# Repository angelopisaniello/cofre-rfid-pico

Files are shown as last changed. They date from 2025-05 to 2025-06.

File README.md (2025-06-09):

# Sistema de Gavetas Inteligentes com Abertura por RFID

## Descrição Geral
Este projeto foi desenvolvido como parte da disciplina **EEN251 - Microcontroladores e Sistemas Embarcados** do Instituto Mauá de Tecnologia.

## 👨‍💻 Integrantes da Equipe

| Nome | RA |
|---|---|
| Angelo Pisaniello Junior | 12.95003-3 |
| Danilo Di Fábio Bueno | 22.00028-3 |
| Daniel F. Soares | 22.01298-2 |

## Descrição do Projeto

O projeto consiste em um sistema embarcado para controle de três gavetas inteligentes com abertura por **RFID**, desenvolvido com o microcontrolador **Raspberry Pi Pico**. As gavetas possuem **solenóides** para travamento/abertura, e o sistema inclui ainda:

- **Teclado matricial** para comandos locais;
- **Display OLED** para exibição de mensagens;
- **LEDs e buzzer** para sinalização visual e sonora;
- **Sensores ópticos** para detecção de estado (aberta/fechada) das gavetas.

Este projeto tem aplicação potencial em **cofres de hotel**, **estações públicas de recarga de celular** ou **armários inteligentes**.

---

## 📋 Requisitos do Sistema

| ID | Requisito | Tipo |
|---|---|---|
| SR-01 | Ser composto por módulos prontos e de fácil acesso | Obrigatório  |
| SR-02 | Controlar a abertura de 3 gavetas de forma independente por meio de autenticação RFID | Obrigatório  |
| SR-03 | Travar e destravar as gavetas utilizando solenoides de 12V | Obrigatório  |
| SR-04 | Detectar o estado (aberta/fechada) de cada gaveta utilizando sensores ópticos | Obrigatório  |
| SR-05 | Fornecer feedback visual através de LEDs indicadores | Obrigatório  |
| SR-06 | Fornecer feedback sonoro através de buzzer | Obrigatório  |
| SR-07 | Permitir comandos e interação local por meio de teclado matricial | Obrigatório  |
| SR-08 | Exibir informações no display OLED (status, mensagens de operação) | Obrigatório  |
| SR-09 | Possuir sistema de proteção elétrica adequado (diodos flyback, MOSFETs para acionamento) | Obrigatório  |
| SR-10 | Ser alimentado por fonte de 12V com corrente suficiente para acionar os 3 solenoides | Obrigatório  |
| SR-11 | Ser montado em uma estrutura mecânica adequada (gaveteiro e caixa segura para o mecanismo) | Obrigatório  |
| SR-12 | Garantir a segurança contra sobreaquecimento dos solenoides com controle de tempo de acionamento  | Obrigatório  |
| SR-13 | Permitir futuras expansões, como comunicação com sistema externo (Wi-Fi, Bluetooth) | Desejável |
| SR-14 | Implementar modo de bloqueio total, caso tentativas de abertura não autorizadas sejam detectadas  | Desejável |

## 📝 Lista de Componentes

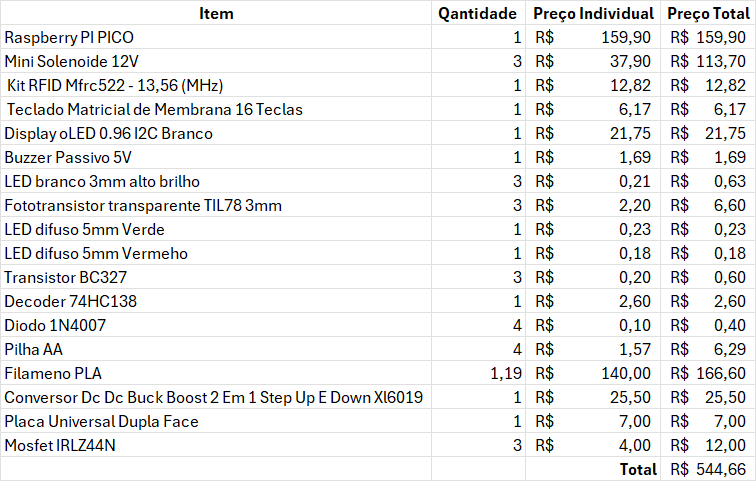
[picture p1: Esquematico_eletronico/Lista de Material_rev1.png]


## Diagrama de Blocos
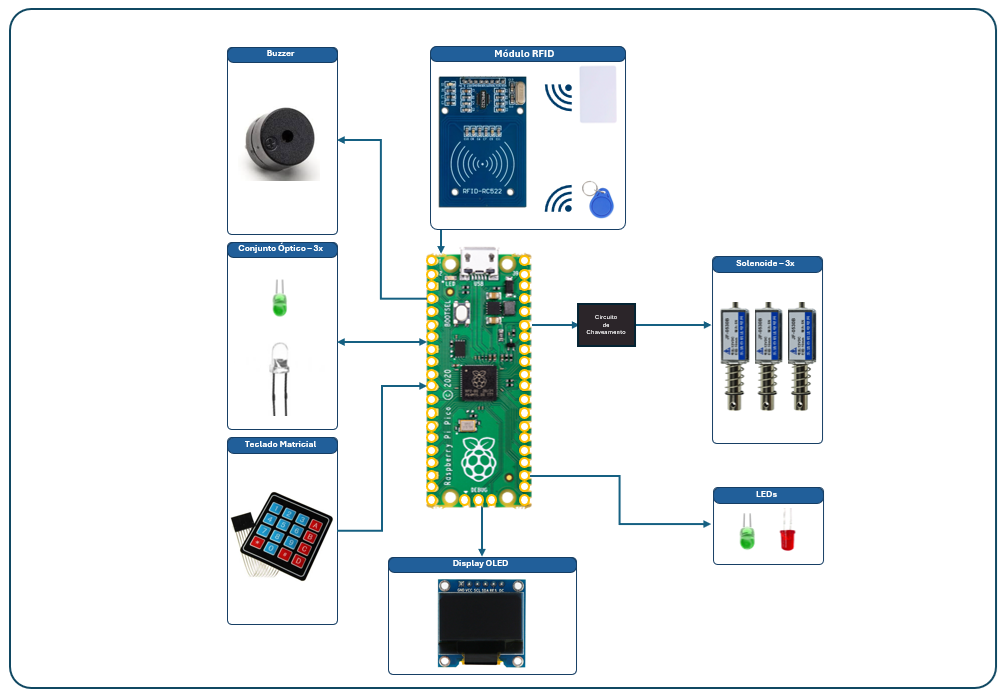
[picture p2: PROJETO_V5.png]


## 📥 Esquemáticos do Circuito Eletrônico

Os diagramas do circuito eletrônico do projeto foram desenvolvidos utilizando o software **KiCad EDA 9.0.2**.

- [Esquemático - Módulo de Controle](https://github.com/angelopisaniello/cofre-rfid-pico/blob/main/Esquematico_eletronico/proj1_sch01.pdf)
- [Esquemático - Módulo de Potência](https://github.com/angelopisaniello/cofre-rfid-pico/blob/main/Esquematico_eletronico/proj1_sch02.pdf)

Os esquemáticos incluem todos os componentes principais do sistema: Raspberry Pi Pico, RFID, LEDs de sinalização, drivers MOSFET, sensores ópticos, entre outros.

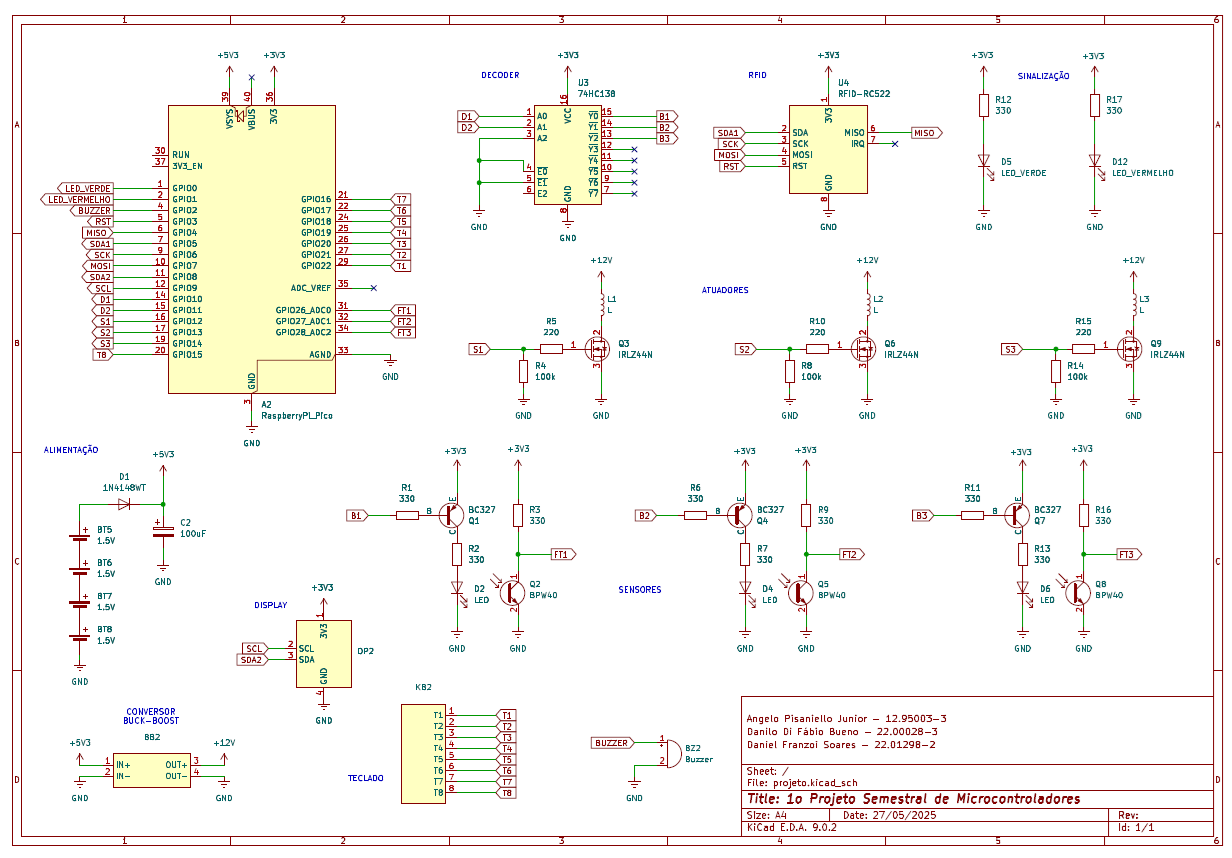
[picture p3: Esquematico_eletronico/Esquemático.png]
.

## 📷 Visualização do Circuito Montado

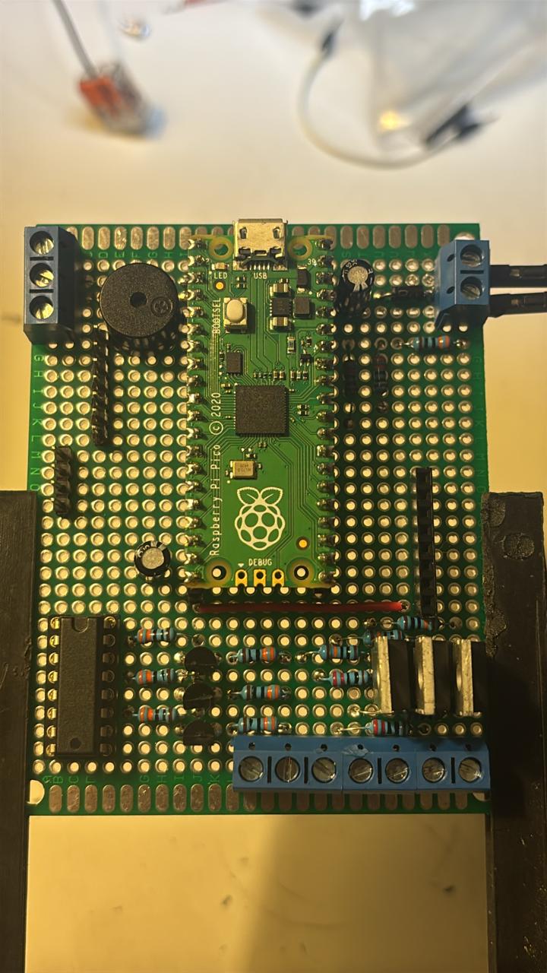
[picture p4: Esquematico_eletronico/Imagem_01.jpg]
image alt
.

## 🛠️ Projeto Mecânico das Gavetas

O projeto das peças mecânicas foi desenvolvido utilizando o software **Autodesk Fusion 360**, versão **2601.1.37 x86_64**, com plano **Estudante**. O ambiente de modelagem foi realizado no **Windows 11 Pro 24H2**.

As peças foram concebidas visando **facilidade de fabricação e montagem**, sendo idealizadas para **impressão 3D** utilizando o material **PLA (Ácido Polilático)**.

### 🎯 Motivos para a escolha do PLA:
- Excelente **custo-benefício**.
- **Facilidade de impressão**, mesmo em impressoras 3D domésticas.
- **Boa resistência mecânica** e **rigidez**, adequada para a estrutura das gavetas.
- Material **biodegradável** e com baixo impacto ambiental.
- **Acabamento estético** superior, com superfície lisa e sem necessidade de pós-processamento complexo.

### 🖥️ Por que escolhemos o Autodesk Fusion 360?
- Ferramenta **profissional e amplamente utilizada** na indústria.
- Permite integração completa entre **modelagem 3D**, **simulações** e **geração de arquivos para impressão (STL)**.
- Licença gratuita para **uso educacional**, ideal para o desenvolvimento acadêmico.
- Ambiente intuitivo, com recursos de **parametrização** e **colaboração em nuvem**.

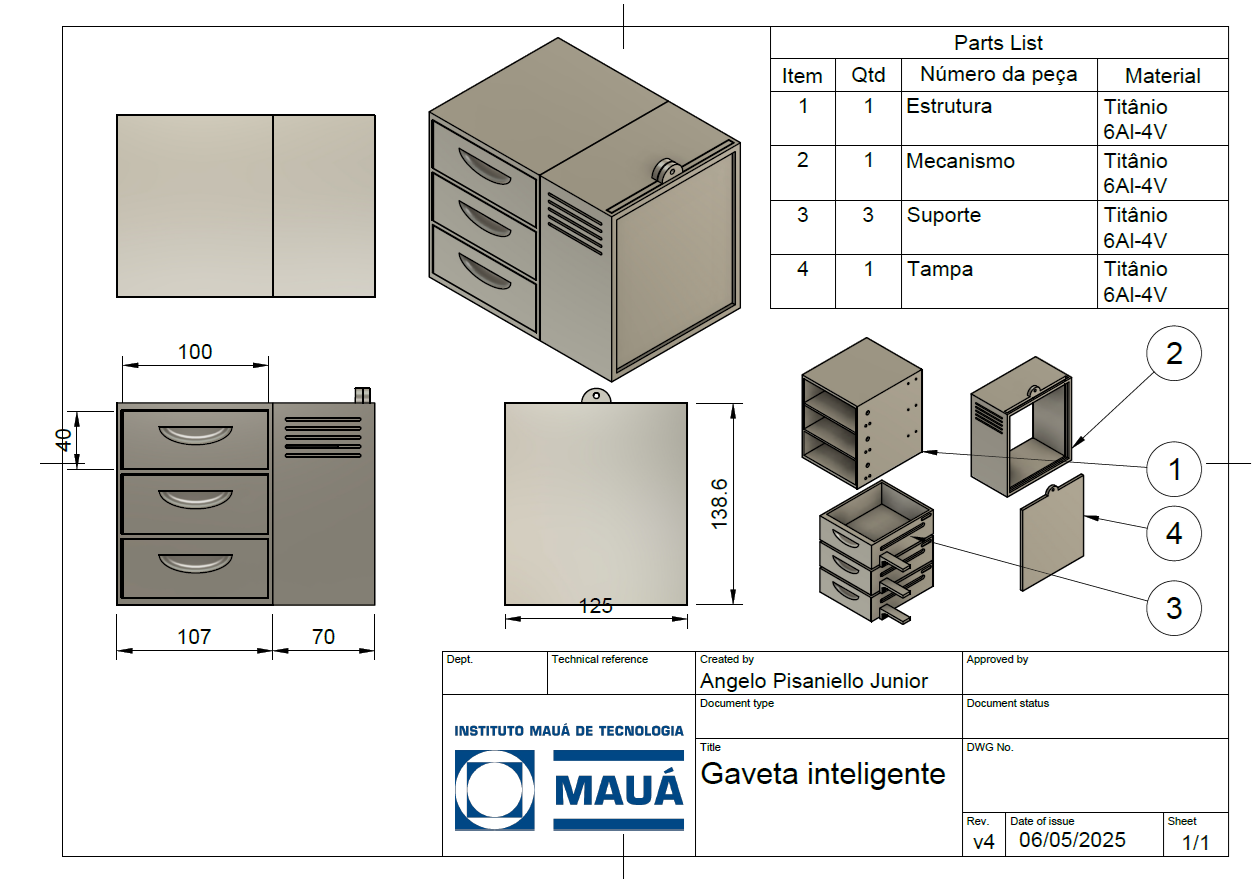
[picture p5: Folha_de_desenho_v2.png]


### 🔐🗄️ Imagem do Produto Final

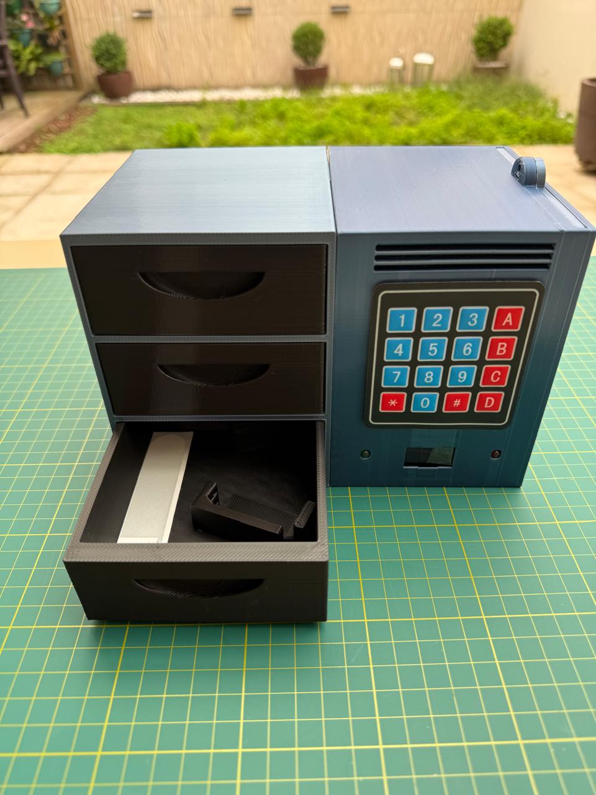
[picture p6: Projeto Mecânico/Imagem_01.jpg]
image alt


- [Arquivo do Projeto do Fusion 360](https://github.com/angelopisaniello/cofre-rfid-pico/blob/8d926f475f4df262f432c6a18744f179cbe58f7a/Projeto%20Mec%C3%A2nico/Angelo%20v4%20v16%20v1.f3d)

## Vídeo Explicativo

- [Link do Youtube](https://youtu.be/eFmRIbqSjfY

## ✅ Conclusão

O projeto apresentado integra hardware, software embarcado e projeto mecânico para demonstrar um sistema de controle de gavetas inteligentes com autenticação por RFID. A solução proposta tem aplicações práticas em segurança e automação, e poderá ser expandida para novas funcionalidades como controle remoto via rede e sensores adicionais.

> Projeto desenvolvido para a disciplina EEN251 - Microcontroladores e Sistemas Embarcados | Instituto Mauá de Tecnologia.

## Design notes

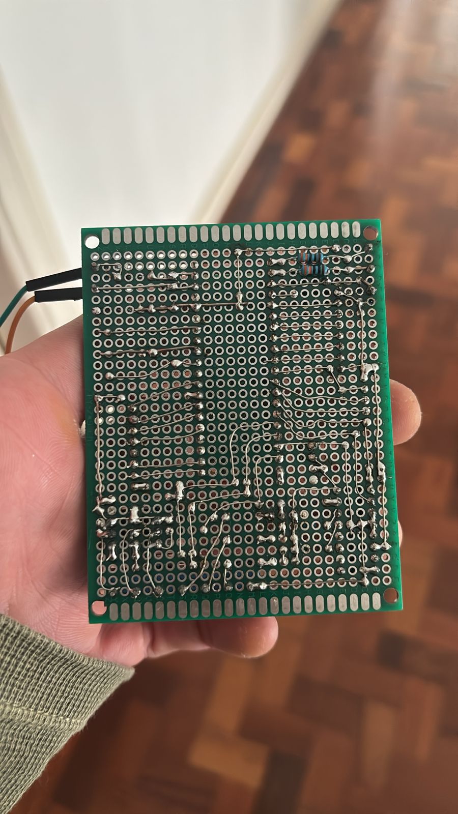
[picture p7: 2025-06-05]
Esquematico_eletronico/Imagem_02.jpg

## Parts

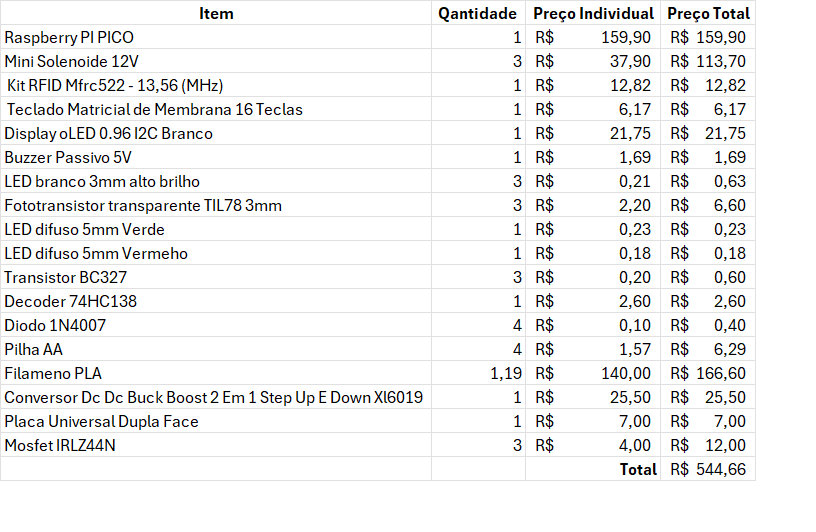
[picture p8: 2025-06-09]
Esquematico_eletronico/Lista de Material.png

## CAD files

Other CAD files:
Projeto Mecânico/Angelo v4 v16 v1.f3d

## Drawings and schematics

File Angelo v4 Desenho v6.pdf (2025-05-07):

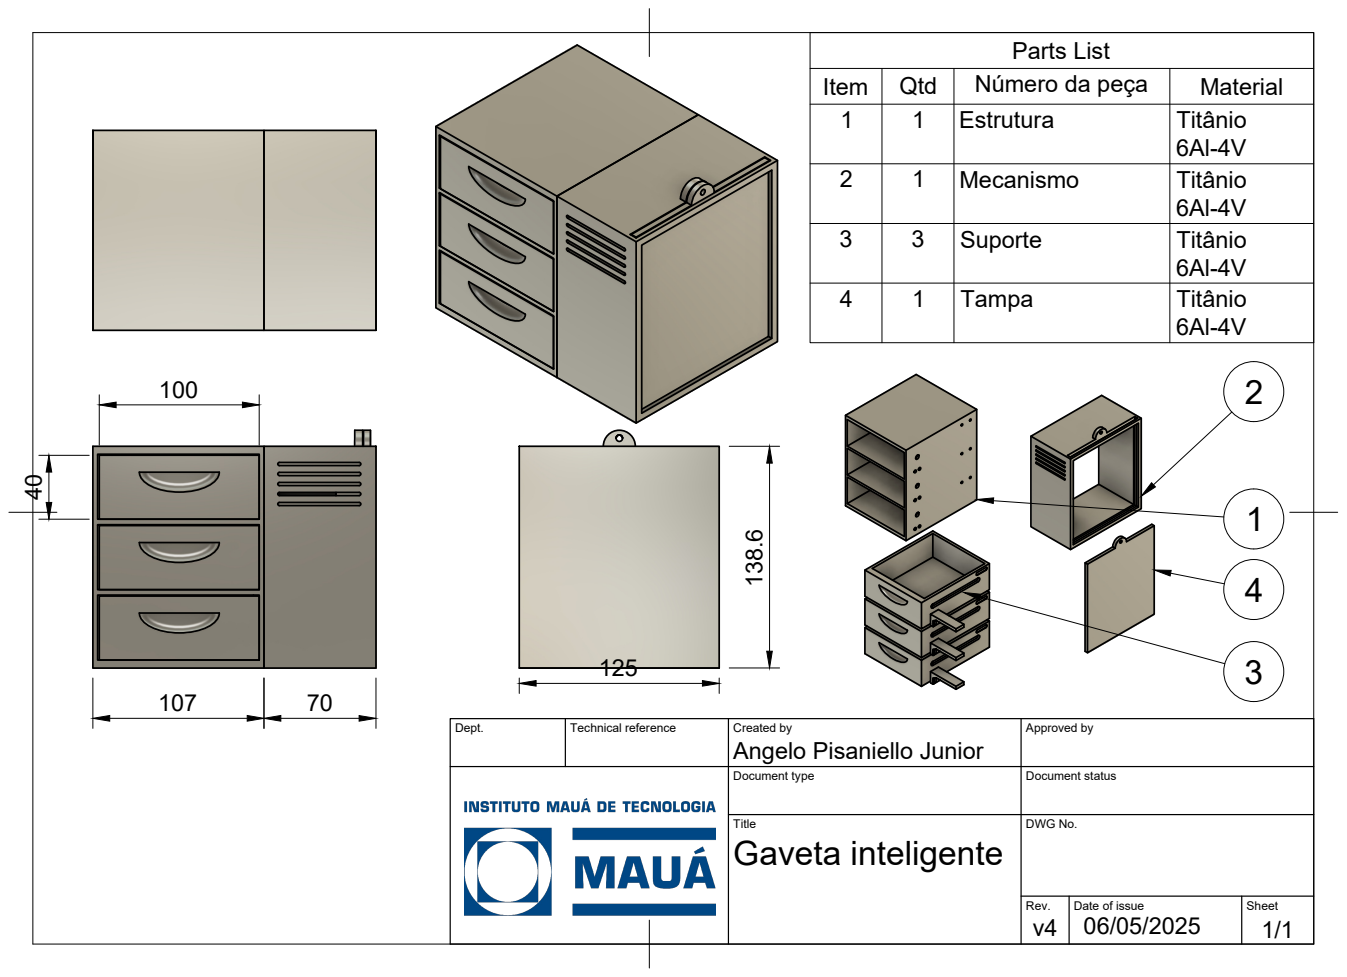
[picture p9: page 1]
Parts List

Item | Qtd | Número da peça | Material
1 | 1 | Estrutura | Titânio 6Al-4V

2 | 1 | Mecanismo | Titânio 6Al-4V

3 | 3 | Suporte | Titânio 6Al-4V

4 | 1 | Tampa | Titânio 6Al-4V

Angelo Pisaniello Junior 138.6

Dept. | Technical reference | Created by | Approved by

Document type | Document status

Title Gaveta inteligente | DWG No.

Rev. v4 | Date of issue 06/05/2025 | Sheet 1/1

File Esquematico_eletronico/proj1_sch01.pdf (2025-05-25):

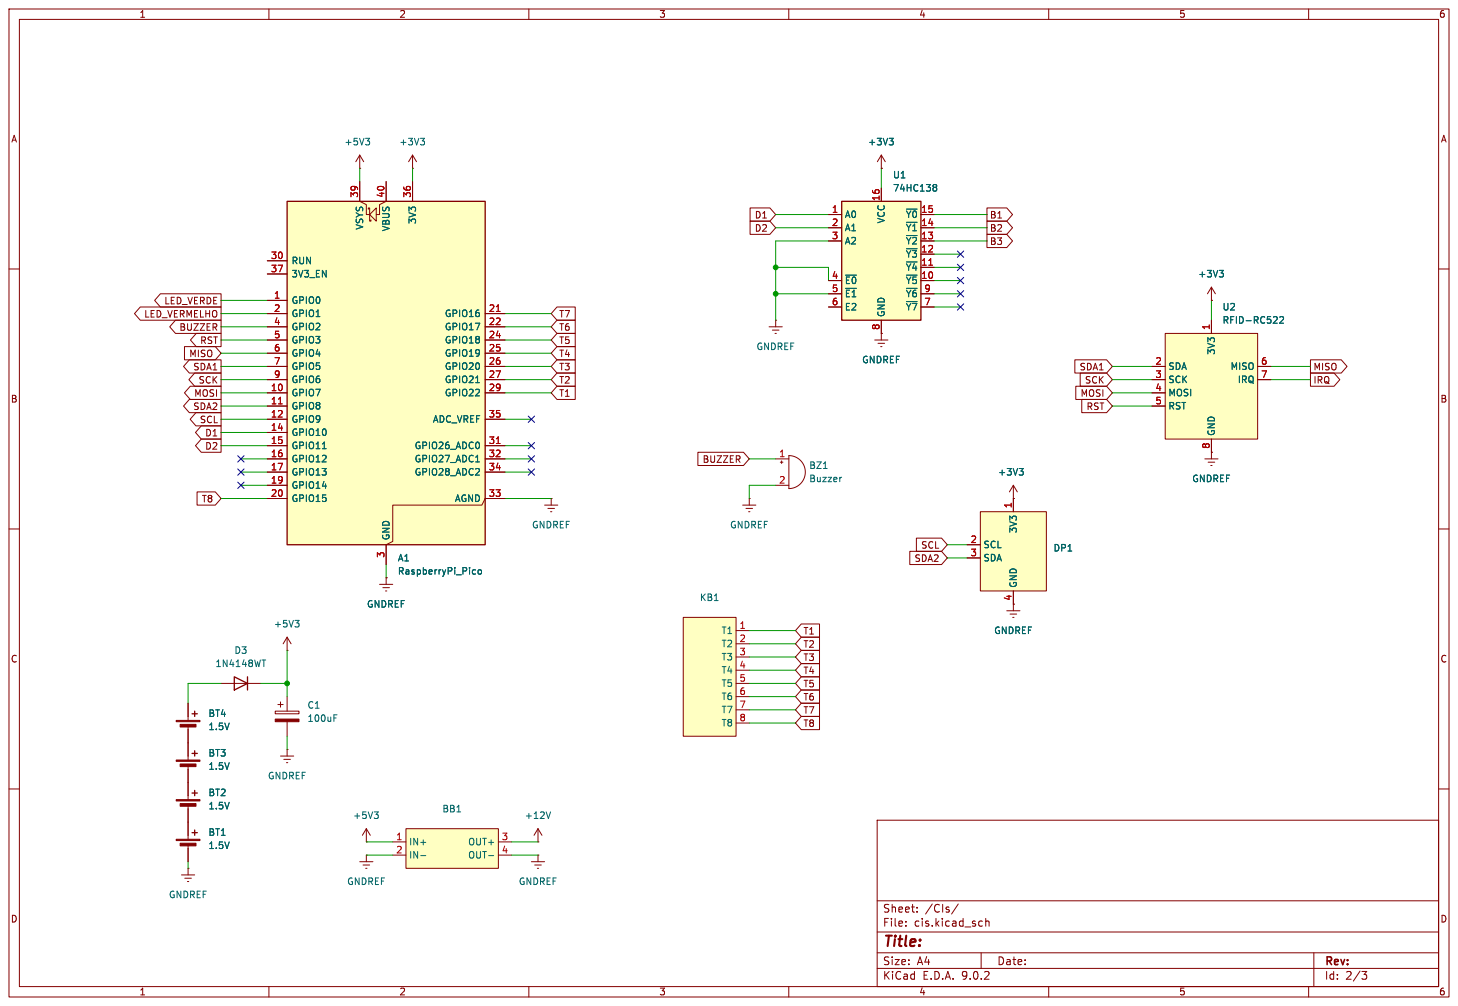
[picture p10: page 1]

Id: 2/3 Title: File: cis.kicad_sch Sheet: /CIs/

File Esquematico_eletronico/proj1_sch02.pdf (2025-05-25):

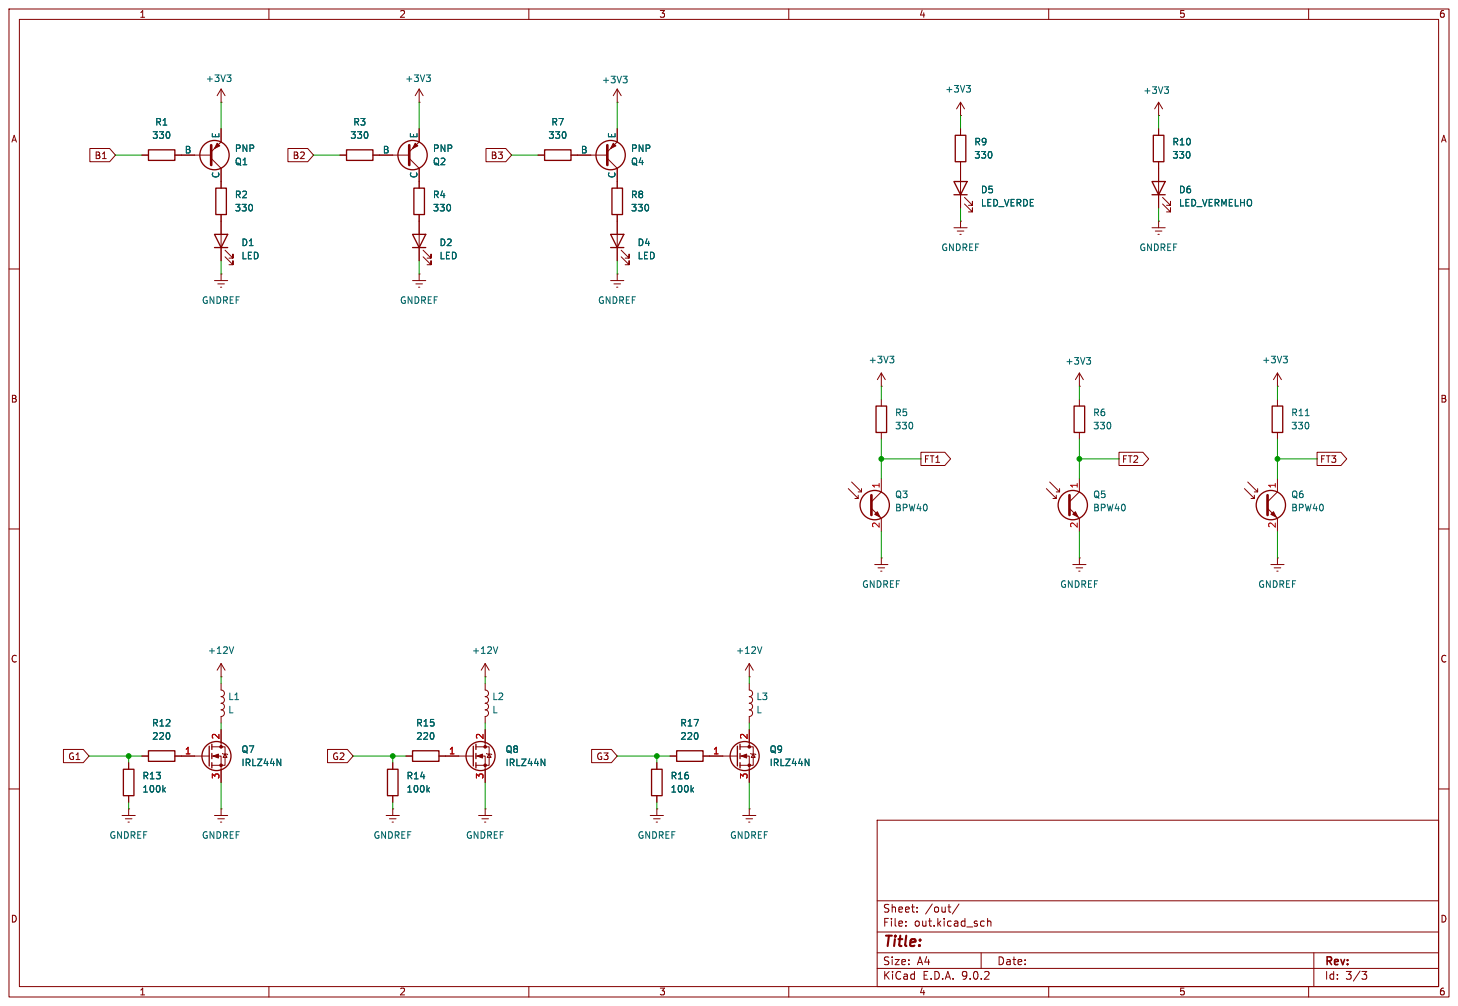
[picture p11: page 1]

Id: 3/3 Title: File: out.kicad_sch Sheet: /out/

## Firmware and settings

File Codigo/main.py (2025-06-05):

# Bibliotecas:
from machine import ADC, Pin 	# ADC =, IOs
import time 	# Temporizacao
import utime 	# Temporizacao
from machine import RTC # Real Time Clock
from machine import I2C 	# I2C
from mfrc522 import MFRC522 # RFID
from ssd1306 import SSD1306_I2C # Display OLED
#---------------------------------------------------------------------------------------------

# Variaveis globais:
WIDTH =128 
HEIGHT= 64
ST = 250 # Tempo de atualizacao em ms
usuarios = { 111111111: "Angelo", 1587063440:"Daniel", 2307218261: "Danilo"} # Dicionarios para os usuarios
gavetas = { "Angelo" : 1, "Daniel": 2, "Danilo": 3} # Dicionario para as gavetas
teclas = [
    ['1', '3', 'A', '2'],
    ['4', '6', 'B', '5'],
    ['7', '9', 'C', '8'],
    ['*', '#', 'D', '0']
] # Teclas
SENHA = "123456" # Senha mestre do cofre
#---------------------------------------------------------------------------------------------

# Mapeamento de Hardware:
#Entradas:
fototransistores = [ ADC(Pin(26)), ADC(Pin(27)), ADC(Pin(28))] # Fototransistores
reader = MFRC522(spi_id = 0, sck = 6, miso = 4, mosi = 7, cs = 5, rst = 3) # Leitor RFID
linhas = [Pin(i, Pin.OUT) for i in (15, 16, 17, 18)]# Linhas do teclado
colunas = [Pin(i, Pin.IN, Pin.PULL_DOWN) for i in (19, 20, 21, 22)] # Colunas do teclado
#Saidas:
decoder = [machine.Pin(10, machine.Pin.OUT), machine.Pin(11, machine.Pin.OUT)] # Decoder
solenoide = [ machine.Pin(14, machine.Pin.OUT), machine.Pin(13, machine.Pin.OUT), machine.Pin(12, machine.Pin.OUT)] # Solenoides
buzzer = machine.Pin(2, machine.Pin.OUT) # Buzzer
i2c=I2C(0,scl=Pin(9),sda=Pin(8),freq=200000) # Display OLED
oled = SSD1306_I2C(WIDTH,HEIGHT,i2c) # Display OLED
#Led_on_board = machine.Pin(25, machine.Pin.OUT) # Led ON Board
gLed = machine.Pin(0, machine.Pin.OUT) # LED verde
rLed = machine.Pin(1, machine.Pin.OUT) # LED vermelho
rtc = RTC() # rtc
#---------------------------------------------------------------------------------------------

# Funcoes:
#def blink(timer): # Alterar estado do LED
 #   led.toggle()
# Funcao para retornar o TimeStamp formatado:
def TimeStamp_to_str( ref ): 
    aux = str(ref[0]) + "-" # AAAA-
    for i in range(1, 6):
        if  ref[i] < 10 : # Menos de dois digitos
            aux += '0'
        aux += str(ref[i]) + "-"*(i<2) + " "*(i==2) + ":"*(i>2 and i < 5) # XX
    return aux ## AAAA-MM-DD HH:MM:SS

#Funcao para retornar o LOG formatado
def LOG_to_str( ts, us, gv): 
    lg = '\n' + TimeStamp_to_str(ts) + ";" + str(us) + ";" + str(gv)
    return lg

#Funcao auxiliar para testar os solenoides
def Testa_solenoides():
    while(1):
        for i in range(3):
            solenoide[i].on()
        time.sleep(4)
        for i in range(3):
            solenoide[i].off()
        time.sleep(4)

# Funcao para tocar a buzzer por um numero de repeticoes
def Campainha( T, n):
    for i in range(n):
        buzzer.on() # Aciona
        time.sleep_ms(int(T/2))
        buzzer.off() # Desliga
        time.sleep_ms( int(T/2))
        
#Funcao para controlar os leds ligados no decoder:
def Decodifica( l ):
    decoder[0].value( l &  1)
    decoder[1].value( l >> 1)

#Funcao para retornar a tecla pressionada (ou se nenhuma foi pressionada
def Tecla():
    for i, linha in enumerate(linhas):
        linha.high()  # Ativa linha atual
        for j, coluna in enumerate(colunas):
            if coluna.value() == 1:
                linha.low()
                return teclas[i][j]
        linha.low()
    return -1

#Funcao para cronometar abertura da gaveta
def Cronometrar_abertura(gav, us ):
    for i in range(4):
        oled.fill(0) # Cor de fundo preta
        print(4-i)
        oled.text("Bem vindo,", 0, 18)
        oled.text(us, 0, 30)
        oled.text("Abrindo " + str(gav) + "...", 0, 45)
        oled.text("Tempo: " + str(4-i), 30, 55)
        oled.show()
        Campainha(100, 1)
        time.sleep(1)
        oled.fill(0) # Cor de fundo preta
    print(0)
    oled.text("Bem vindo,", 0, 18)
    oled.text(us, 0, 30)
    oled.text("Abrindo " + str(gav) + "...", 0, 45)
    oled.text("Tempo: 0", 30, 55)
    oled.show()
    
#Funcao para abrir uma gaveta
def Abrir_gaveta( gav, us):
    oled.fill(0) # Cor de fundo preta
    oled.text("Bem vindo,", 0, 18)
    oled.text(us, 0, 30)
    Campainha(200, 3)
    oled.text("Abrindo " + str(gav) + "...", 0, 45)
    oled.show()
    solenoide[gav - 1].on() # Retrai o solenoide
    gLed.on() # Liga o LED de sinalizacao verde
    Cronometrar_abertura( gav, us ) # Mostra o cronometro
    solenoide[gav-1].off() # Desliga o solenoide
    print("Gaveta " + str(gav) + " aberta")
    time.sleep(0.5) # Aguarda 0.5s
    ocr = 0 # Numero de ocorrencias
    buz = 0 # Auxiliar para buzzer
    flag = time.ticks_ms() # Reseta a flag (cronometro)
    oled.fill(0) # Cor de fundo preta
    oled.text("Feche a gaveta", 0, 20)
    oled.show()
    Acende_gaveta( gav ) #
    time.sleep(3)
    while ocr < 3:
        valor = fototransistores[gav-1].read_u16() # Conversao AD
        print("adc = " + str(valor)) # Apenas depuracao
        if (valor< 57900 and gav == 3) or (valor < 60500 and gav == 2) or (valor < 62000 and gav == 1) or Tecla() == '*': # Gaveta esta fechada
            ocr = ocr + 1 # Incrementa o numero de ocorrencias
        else:
            ocr = 0 # Zera o numero de ocorrencias
        if time.ticks_diff(time.ticks_ms(), flag) > 60000: # Gaveta a mais de 60 segundos aberta
            buzzer.value( buz < 3)
            buz = (buz + 1) % 6
        time.sleep_ms(20) # Aguarda 20 ms
    gLed.off() # Desliga o LED de sinalizacao verde                
    Acende_gaveta( -1 ) # Apaga os LEDs            
    
def Menu_principal():
    oled.fill(0) # Cor de fundo preta
    oled.text("Cofre 1.0", 30, 5)
    oled.text("Aproxime a TAG", 8, 20)
    oled.show()
    
def Menu_mestre(): # Menu de gerenciamente
    oled.fill(0) # Cor de fundo preta
    oled.text("Gerenciamento", 25, 5)
    oled.text("1 - Abrir gaveta 1", 0, 15)
    oled.text("2 - Abrir gaveta 2", 0, 25)
    oled.text("3 - Abrir gaveta 3", 0, 35)
    oled.text("4 - Retroceder", 0, 45)
    oled.show()
    
def Acende_gaveta( gav ):
    if( gav == 3):
        Decodifica(1)
    elif gav == 2:
         Decodifica(2)           
    elif gav == 1:
        Decodifica(0)
    else:
        Decodifica(3)
#---------------------------------------------------------------------------------------------
    
# Configuracoes Iniciais (Setup):    
#timer.init(freq=2.5, mode=machine.Timer.PERIODIC, callback=blink)

print("Configuracoes Termidas")
print("Entrando na Rotina Principal...")
time.sleep_ms(250) # Aguarda 250 ms
#rtc.datetime((2024, 4, 30, 4, 16, 26, 30, 0)) # Configura o horario
gLed.off() # Desliga o LED de sinalizacao verde   
rLed.off() # Desliga o LED de sinalizacao verde
buzzer.off() # Desliga o buzzer
Decodifica(3) # Leds desligados
for i in range(3): # 3 solenoides
    solenoide[i].off() # Desliga os solenoides
oled.fill(0) # Cor de fundo preta
oled.text("Cofre 1.0", 30, 5)
oled.show()
#---------------------------------------------------------------------------------------------
# while 1:
#     solenoide[3 - 1].on()
#     time.sleep(4)
#     solenoide[3 - 1].off()
#     time.sleep(4)
# Rotina Principal (Loop):
# teste = 0
# while 1:
#     print(Tecla())
#     time.sleep_ms(100) # Aguarda

# while 1:
#     solenoide[0].on()
#     Decodifica(1)
#     time.sleep_ms(3500) # Aguarda
#     Decodifica(0)
#     solenoide[0].off();
#     time.sleep_ms(5000) # Aguarda
teste = 0
Acende_gaveta( -1 )
# # while True:
# #     # Testa leitura dos ADCs
# #     for i in range(3):
# #         print(f"ADC {i}: {fototransistores[i].read_u16()}")
# #     time.sleep(0.5)
# while 1:
#     #Decodifica(0/)
#     fototransistores[0] = ADC(Pin(28))
#     print( fototransistores[0].read_u16())
#     time.sleep(0.2)
# 
# while 1:
#     Decodifica(teste)
#     teste = (teste + 1) % 4
#     print(teste)
#     print( fototransistores[teste-1].read_u16())
#     time.sleep_ms(3000) # Aguarda
flag = time.ticks_ms() # Seta a flag (cronometro)
while 1:
    Menu_principal()
    if ( Tecla() != '*'): # * nao pressionado
        flag = time.ticks_ms() # Reseta a flag (cronometro)
    print(time.ticks_diff(time.ticks_ms(), flag))    
    if ( time.ticks_diff(time.ticks_ms(), flag) >= 10000): # Pressionou por mais de 10 segundos:
        Campainha(100, 5)
        print("Aguarde...")
        oled.fill(0) # Cor de fundo preta
        oled.text("Aguarde...", 30, 25)
        time.sleep_ms(500) # Aguarda
        oled.show()
        while (Tecla() == "*"): # Ainda nao soltou o *
            oled.text("Solte o *", 40, 25)
            time.sleep_ms(50) # Aguarda
        flag = time.ticks_ms() # Flag de inicio da subrotina de menu
        tentativa = 1 # Tentativas
        senha = "" # senha digitada
        while time.ticks_diff(time.ticks_ms(), flag) < 10000 and tentativa <= 3  : # Ate 10 segundos de inatividade ou 3 tentativas
            oled.fill(0) # Cor de fundo preta
            oled.text("Digite a senha:", 10, 20)
            oled.text("*" * len(senha), 32, 40)
            oled.show()
            aux = Tecla() # Le o teclado
            if aux != -1: # Pressionou alguma tecla
                Campainha(300, 1) # Soa
                senha = senha + aux # adiciona a tecla pressionada a senha
                while Tecla() == aux: # Enquanto estiver pressionado
                    time.sleep_ms(50) # Aguarda
                flag = time.ticks_ms() # Reseta a flag (cronometro)   
            print(str(time.ticks_diff(time.ticks_ms(), flag)) + "   " + senha)
            if ( len(senha) == 6):
                print("Mestre")
                if ( senha == SENHA): # Senha correta
                    tentativa = 0
                    Campainha(200, 2)
                    flag = time.ticks_ms() # Reseta a flag (cronometro)   
                    aux = -1
                    while time.ticks_diff(time.ticks_ms(), flag) < 10000 and aux != '4': # Ate 10 segundos de inatividade ou opcao por voltar
                        Menu_mestre()
                        aux = Tecla()
                        print("aux = " + str(aux))
                        if( aux != -1 and aux != '4'):
                            while Tecla() == aux: # Enquanto estiver pressionado
                                time.sleep_ms(50) # Aguarda
                            Abrir_gaveta( int(aux), "Mestre" )
                            flag = time.ticks_ms() # Reseta a flag (cronometro)
                        tentativa = 4 # Forca a saida
                        time.sleep_ms(50) # Aguarda
                else: # Senha incorreta
                    Campainha(200, 5)
                    tentativa = tentativa + 1 # nova tentativa
                    senha = ""
                flag = time.ticks_ms() # Reseta a flag 
            time.sleep_ms(50) # Aguarda
    reader.init() # Inicia o leitor
    (stat, tag_type) = reader.request(reader.REQIDL) # Leitura
    if stat == reader.OK: # Se a leitura foi bem sucedida
        (stat, uid) = reader.SelectTagSN()
        if stat == reader.OK:
            card = int.from_bytes(bytes(uid),"little",False)
            print("CARD ID: "+ str(card) )
            if card in usuarios: # Cartao valido
                timeStamp = rtc.datetime() # Horario para o LOG
                usuario = usuarios[card] # Usuario atual
                gaveta = gavetas[usuario]
                log = LOG_to_str(timeStamp, usuario, gaveta) # Obtem a string do LOG
                print(log)
                print("Usario Identificado: " + usuario) # Informa o usuario
                print("Abrindo gaveta " + str(gaveta) + "...") # Informa a gaveta correspondente
                Abrir_gaveta( gaveta, usuario)
            else: # TAG nao encontrada
                rLed.on() #Liga o LED de sinalizacao vermelho     
                buzzer.on() # Aciona
                print("TAG nao encontrada")
                oled.text("TAG invalida", 0, 25)
                oled.text("Tente novamente", 0, 50)
                oled.show()
                time.sleep(1) # Aguarda 1s
                buzzer.off()# Desliga
                rLed.off() # Desliga o LED de sinalizacao vermelho
            flag = time.ticks_ms() # Flag de inicio da subrotina de menu
    time.sleep_ms(100) # Aguarda 

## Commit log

2025-05-25 Create Pasta para armazenar esquemáticos eletrônicos do projeto.
2025-05-25 Pasta para armazenar esquemáticos eletrônicos do projeto.
2025-06-04 Update main.py
    Adição da leitura dos fototransistores e decodificação para os LEDs.
2025-06-04 Update main.py
    Desvio para rotina de senha.
2025-06-04 Update main.py
    Buzzer integrada com rotina de senha. Sistema anti-debouncing. Correções visuais no menu de senha.
    [main.py]
2025-06-04 Update main.py
    Rotina de gerenciamento com escape. Síntese da função de abertura.
2025-06-04 Update main.py
    Rotina completa de abertura e fechamento da gaveta.
2025-06-05 Update main.py
    Correção de pinos do RFID (Problema na leitura do ADC).
    [main.py]
2025-06-05 Update main.py
    Calibração dos fototransistores por gaveta. Detecção de status operando.
2025-06-05 Update main.py
    Correção valor gaveta. Diminuição do tempo de varredura.
2025-06-05 Update main.py
    Pinos dos solenoides mapeados.
2025-06-09 Update README.md
    Adição do link para o vídeo.
